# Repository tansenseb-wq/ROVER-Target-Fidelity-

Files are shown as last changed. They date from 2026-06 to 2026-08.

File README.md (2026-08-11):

# ROVER "Target Fidelity"

A low-budget, 6-wheel autonomous rover that drives itself through rough terrain, collects soil and plant samples, and runs onboard biology and geology tests — all built from 3D-printed parts, off-the-shelf motors, and open-source software. Or so I hope.

## Status

No driving demo yet — here's where the build actually stands:

| Area | State |
|---|---|
| Suspension + wheel-corner CAD | Designed and validated as standalone assemblies (steering geometry, printed bearing, real angles) |
| Differential (balancín + bieletas) | Geometry defined (325 mm 1:1 ratio); hardware not sourced yet |
| BOM | Mobility, chassis frame, filament, and the brain are priced in a real quote; chassis panels, battery, and lab hardware still need quotes |
| Firmware | Not started |
| Sampling arm / lab / vision | CAD and hardware selection in progress, no integration yet |

See the steering knuckle actually moving in [Wheel-corner assembly](#wheel-corner-assembly) below.

---

## What it does

- **Drives itself** — autonomous navigation with SLAM mapping and AR marker detection
- **Handles rough terrain** — rocker-bogie passive suspension (inspired by JPL's open-source rover) keeps all 6 wheels on the ground on dirt, gravel, and grass
- **Real differential** — a balancín + bieletas linkage (like the actual JPL rover) keeps the chassis level when the two sides climb at different heights
- **Collects samples** — a 3-DOF robotic arm with a soil scoop and sealed sample container, controlled by inverse kinematics
- **Runs field biology** — automated Biuret protein test (CuSO₄ + NaOH mix) and plant pigment detection, read by an onboard RGB color sensor
- **Measures soil moisture** — capacitive sensor for real-time geology data
- **Can be driven remotely** — full teleop mode with live camera feed over local WiFi

---

## Key specs

| Spec | Value |
|---|---|
| Chassis body | 900 × 600 mm |
| Wheelbase | 1000 mm |
| Wheel diameter | 200 mm |
| Top speed | ~150 mm/s |
| Obstacle clearance | 300 mm (1.5× wheel Ø) |
| Ground clearance | ~248 mm |
| Estimated mass | ~30 kg |
| Suspension | Passive rocker-bogie, 6 wheels |
| Differential | Real (balancín + bieletas, chassis-leveling) |
| Steering | 4 corner wheels (servo) |

---

## Subsystems

| Subsystem | Key components |
|---|---|
| Chassis | Aluminum 2020 extrusion + PLA/PETG 3D-printed joints |
| Mobility | 6× JGB37 DC motors, BTS7960 drivers, TPU wheels, 2× 448 CPR optical encoders |
| Differential | Balancín + 2 bieletas with ball-joint ends |
| Steering | 4× MG995R servos + PCA9685, printed-bearing knuckle (see below) |
| Brain | Arduino UNO Q (Linux Cortex-A53 + realtime Cortex-M33, one board) |
| Vision | WIP |
| Navigation | WIP |
| Sampling arm | 4× SG51R mini servos, WIP structure |
| Lab | TCS34725 color sensor, peristaltic pump, syringe dispenser |
| Geology | Capacitive soil moisture sensor |

---

## Wheel-corner assembly

Each steering wheel (front-left/right, rear-left/right) is a servo, a printed knuckle, a coupler, and the wheel itself, all validated as a standalone assembly (`Ensamble llanta` / `Ensamble llanta Largo`) before going into the full rover.

- **Geometry adapted from a proven reference** — the servo coupler, servo horn, and wheel-joint pieces come from the "Mars Rover Perseverance Replica" build rather than being designed from scratch. The 37 mm gearmotor (6 mm D-shaft, 31 mm bolt circle) drops straight into the reference's wheel-joint cavity with no scaling.
- **Printed bearing, not a bought one** — the knuckle carries a print-in-place ball bearing (OpenSCAD + BOSL2, "635" size: ID5/OD19/W6mm, dumbbell rollers) instead of a purchased bearing.
- **Socket angle comes from the live model** — the socket tilts so the servo's steering axis is exactly vertical despite sitting on an angled rocker/bogie arm: **30°** at the front/rocker corner, **10°** at the rear/bogie corner, both measured from the actual Fusion assembly rather than assumed.
- **Mirrored for both sides** — all three knuckle variants (`JuntaLlanta`, `JuntaLlantaEstatica`, `JuntaLlantaDireccion`) have mirrored left-side counterparts (`...I` suffix) so the 6-wheel layout is symmetric.

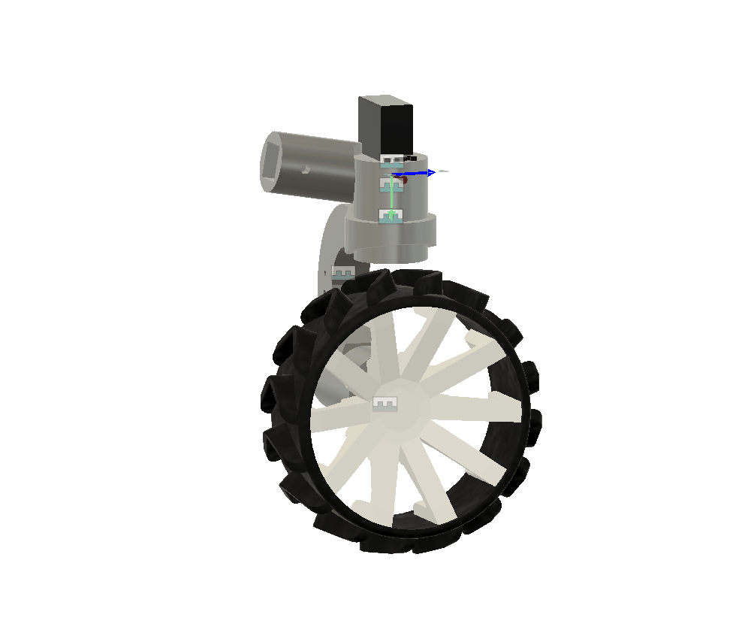
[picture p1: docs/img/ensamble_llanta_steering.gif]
Steering geometry in motion — one wheel-corner assembly sweeping through its steering range


*The steering knuckle (servo + printed bearing + wheel) swinging through its range in Fusion, captured directly from the live model. Full field-test footage still coming.*

---

## Bill of Materials

[`BOM/bom_rover.csv`](BOM/bom_rover.csv) lists every part that's actually been priced, with real quantities, real COP prices, and where each one mounts on the rover — comma-delimited, one quote as the single source of truth (no placeholder/estimate rows).

**Cotizado** (priced out in a real quote — Cotización S174842, I+D Didácticas Electrónicas, COP $2,216,852 with IVA, nothing purchased yet): all 6 JGB37 motors + 3 BTS7960 drivers + steering/arm servos + PCA9685, 13 m of 2020 aluminum profile + T-nuts, PETG/TPU filament, the Arduino UNO Q brain, 2× 448 CPR optical encoders, plus assorted cabling and small hardware.

**Still needed but not priced yet:** round aluminum tube + steel axle for the differential, the acrylic/MDF lid, the LiPo battery + charger, and the lab-module hardware (color sensor, pumps, syringe dispenser) — left out of the CSV until there's a real quote for them, rather than carrying rough guesses.

---

## Printed parts — quick guide

### A couple of things worth knowing before printing

- **The joints set all the angles**, so the aluminum tubes are cut straight at 90°. No mitering needed — that's the whole point of the printed joints.
- **All three wheel mounts share the same 90 mm drop** (socket to wheel center). That's what keeps the three wheels level on the ground — don't change it on just one.
- **The differential bieletas need ball joints on both ends** — a rigid connection binds the linkage. The 1:1 ratio (balancín arm = clamp offset = 325 mm, measured off the real `Diferencial` part) is what keeps the leveling symmetric.
- **Joint walls are 5 mm** — don't go thinner or the M5 bolts pull out of the PETG under load.

Print-ready STL files for every finished functional part live in [`Parts/STL-parts`](Parts/STL-parts), organized by subsystem (`Bogie`, `Direccion`, `Llantas`) rather than by print settings — CAD source stays in Fusion, this folder is just the slicer-ready output.

---

## Build journal

The full design log — why rocker-bogie, the math behind the geometry, dead ends, and every decision along the way — is in [`Journal/Librito_Rover x_x (CreacionSistemaMecanico) .pptx`](Journal/Librito_Rover%20x_x%20%28CreacionSistemaMecanico%29%20.pptx). It's a running notebook, not a polished report; open it in PowerPoint/Slides to read or add to it.

---

## Credits

- Suspension design heavily inspired by [NASA JPL Open Source Rover](https://github.com/nasa-jpl/open-source-rover) 

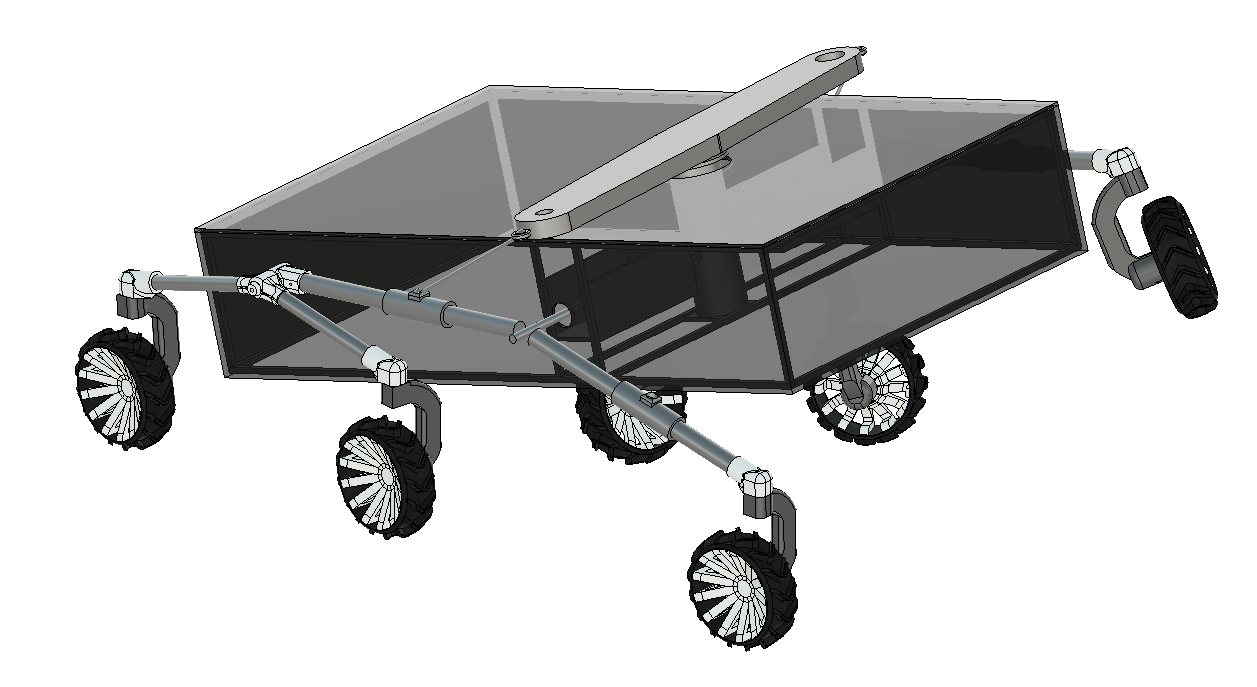
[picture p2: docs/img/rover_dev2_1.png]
Rover dev 2 — isometric view


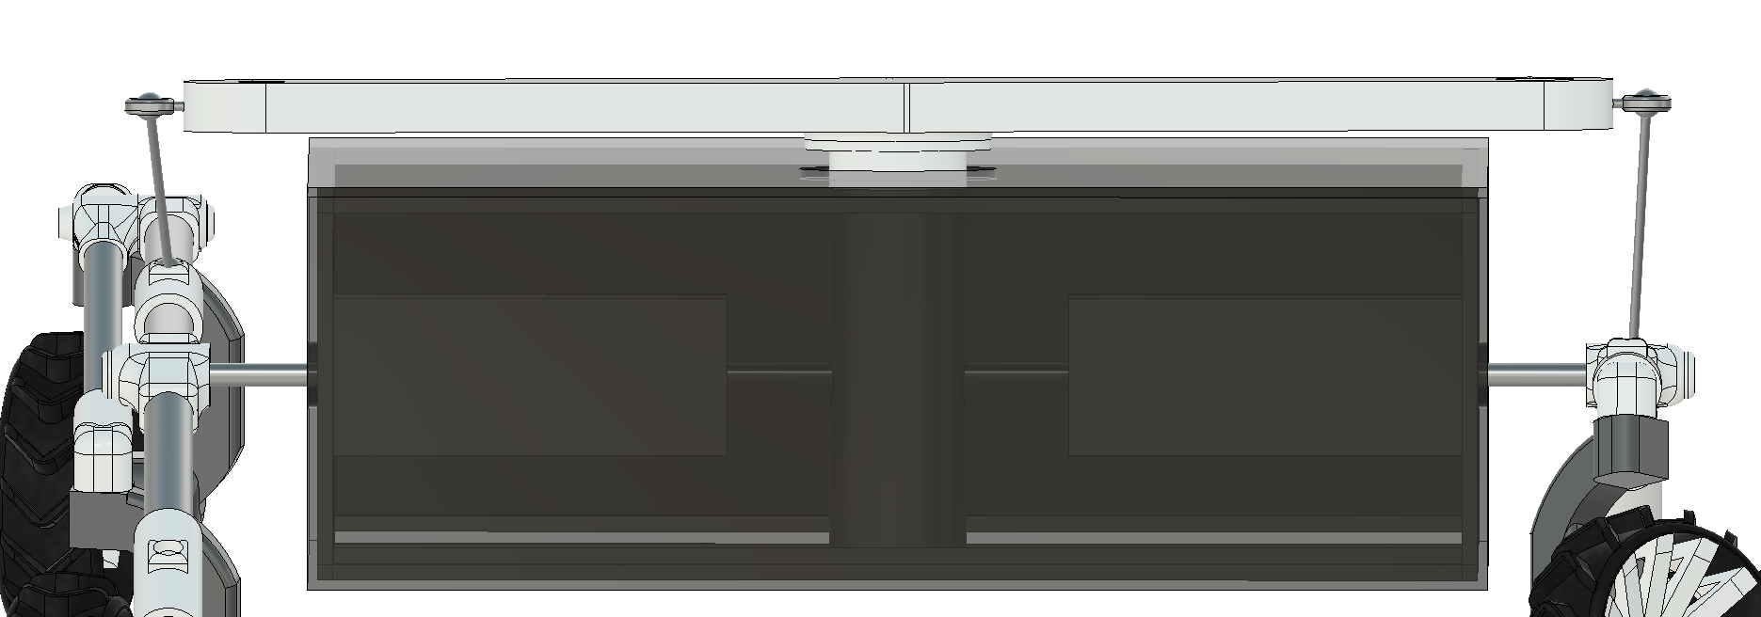
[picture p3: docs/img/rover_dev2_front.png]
Rover dev 2 — front view showing the differential


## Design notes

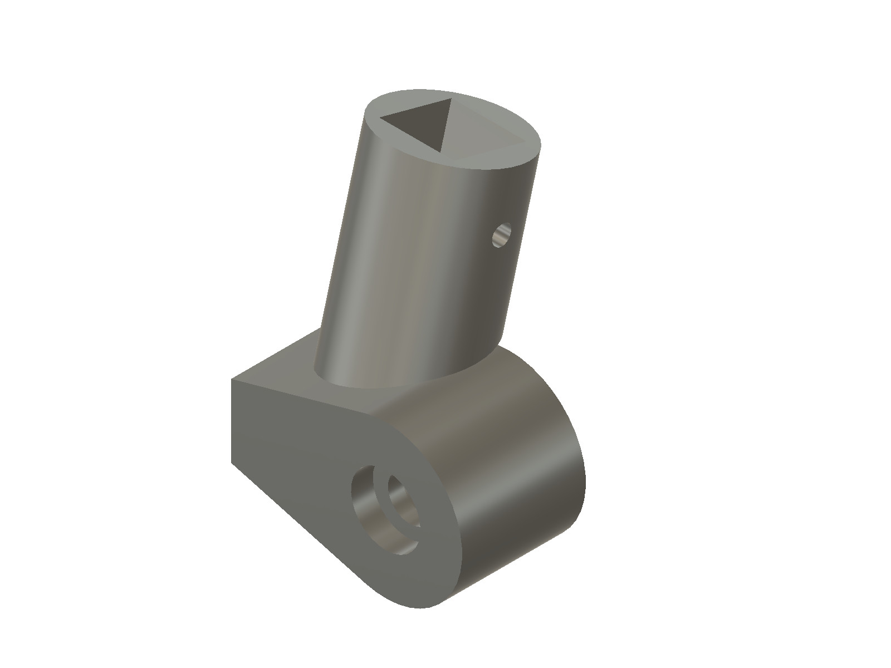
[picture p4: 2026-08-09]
docs/img/junta_llanta_direccion.png

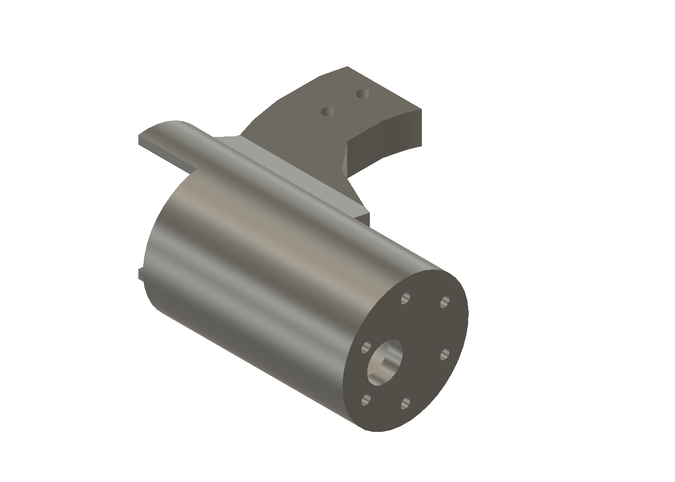
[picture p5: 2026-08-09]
docs/img/wheel1_joint_p2_motor_mount.png

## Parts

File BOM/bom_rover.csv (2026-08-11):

Categoria | Parte | Cantidad | PrecioUnitario_COP | Subtotal_COP | Fuente | Estado | Montaje
Movilidad | Motorreductor JGB37 12V 100RPM | 6 | 73613 | 441678 | ELECTRONICA I+D S.A.S. (Cotizacion S174842) | Cotizado | Junta de rueda (Bogie) - motor de cada una de las 6 ruedas
Movilidad | Driver BTS7960 43A | 3 | 29076 | 87228 | ELECTRONICA I+D S.A.S. (Cotizacion S174842) | Cotizado | Chasis interior - placa de electronica de potencia
Movilidad | Servo MG995R 4.8-7.2V 13Kg/cm (direccion, 4 ruedas) | 4 | 20700 | 82800 | ELECTRONICA I+D S.A.S. (Cotizacion S174842) | Cotizado | Junta de rueda (Bogie) - direccion de las 4 ruedas de esquina
Movilidad | Controlador PCA9685 (16 ch PWM, sin ensamblar) | 1 | 15126 | 15126 | ELECTRONICA I+D S.A.S. (Cotizacion S174842) | Cotizado | Chasis interior - placa de electronica, junto al Arduino UNO Q
Movilidad | Eje metalico [EJE-1005] 100x5 mm | 3 | 2904 | 8712 | ELECTRONICA I+D S.A.S. (Cotizacion S174842) | Cotizado | Junta de rueda (Bogie) - eje servo-rodamiento-rueda en JuntaLlantaDireccion/JuntaLlanta
Movilidad | Rodamiento con brida MF105ZZ (ID5/OD10/H4 mm) | 5 | 3388 | 16940 | ELECTRONICA I+D S.A.S. (Cotizacion S174842) | Cotizado | Junta de rueda (Bogie) - soporte del eje
Movilidad | Encoder optico 448 CPR (eje de 37 mm, para motorreductor) | 2 | 32900 | 65800 | ELECTRONICA I+D S.A.S. (Cotizacion S174842) | Cotizado | Junta de rueda (Bogie) - acoplado al eje trasero del motorreductor
Chasis | Perfil aluminio 2020V-N2 (por m, CNC) | 13 | 24923 | 323995 | ELECTRONICA I+D S.A.S. (Cotizacion S174842) | Cotizado | Chasis - marco estructural
Chasis | Tornillo en T M5x12 para perfil 2020 | 20 | 756 | 15120 | ELECTRONICA I+D S.A.S. (Cotizacion S174842) | Cotizado | Chasis - union de perfiles y placas
Impresion 3D | Filamento PETG Blanco 1kg | 1 | 70300 | 70300 | ELECTRONICA I+D S.A.S. (Cotizacion S174842) | Cotizado | Consumible - no se monta
Impresion 3D | Filamento PETG Gris 1kg | 2 | 70300 | 140600 | ELECTRONICA I+D S.A.S. (Cotizacion S174842) | Cotizado | Consumible - no se monta
Impresion 3D | Filamento TPU 95A Negro 800g | 1 | 90800 | 90800 | ELECTRONICA I+D S.A.S. (Cotizacion S174842) | Cotizado | Consumible - no se monta
Cerebro y control | Arduino UNO Q (RAM 2GB, eMMC 16GB, Cortex-A53 + Cortex-M33) | 1 | 189000 | 189000 | ELECTRONICA I+D S.A.S. (Cotizacion S174842, 10% desc.) | Cotizado | Chasis interior - placa de electronica (cerebro)
Cerebro y control | Pantalla OLED 2.42" SSD1309 Blanco | 1 | 45546 | 45546 | ELECTRONICA I+D S.A.S. (Cotizacion S174842) | Cotizado | Chasis - panel frontal/superior visible
Cerebro y control | Conversor DC/DC reductor 300W 20A (alimentacion principal) | 1 | 22185 | 22185 | ELECTRONICA I+D S.A.S. (Cotizacion S174842) | Cotizado | Chasis interior - compartimento de energia
Cerebro y control | Modulo conversor DC-DC LM2576HV (salida ajustable, 3A) | 1 | 11900 | 11900 | ELECTRONICA I+D S.A.S. (Cotizacion S174842) | Cotizado | Chasis interior - compartimento de energia
Energia | Cable siliconado 10AWG Rojo (bateria) | 1 | 18824 | 18824 | ELECTRONICA I+D S.A.S. (Cotizacion S174842) | Cotizado | Chasis interior - linea principal de bateria
Electronica y cableado | Dispensador de cable siliconado 18AWG (5 colores) | 1 | 43697 | 43697 | ELECTRONICA I+D S.A.S. (Cotizacion S174842) | Cotizado | Chasis interior - junto a la placa de electronica
Electronica y cableado | Cable Dupont M/M 10cm (paquete x10, colores) | 3 | 1700 | 5100 | ELECTRONICA I+D S.A.S. (Cotizacion S174842) | Cotizado | Chasis interior - junto a la placa de electronica
Electronica y cableado | Cable Dupont M/H 10cm (paquete x10, colores) | 3 | 1700 | 5100 | ELECTRONICA I+D S.A.S. (Cotizacion S174842) | Cotizado | Chasis interior - junto a la placa de electronica
Electronica y cableado | Pelacable multifuncional AWG 22-10 | 1 | 12600 | 12600 | ELECTRONICA I+D S.A.S. (Cotizacion S174842) | Cotizado | Chasis interior - junto a la placa de electronica
Laboratorio | Varilla trapezoidal roscada M8 paso 1mm, 1m (husillo dispensador/jeringa) | 1 | 39100 | 39100 | ELECTRONICA I+D S.A.S. (Cotizacion S174842) | Cotizado | Modulo de laboratorio - husillo del dispensador de jeringa
Brazo de muestreo | Mini servo SG51R Tower Pro 5g (brazo) | 4 | 24200 | 96800 | ELECTRONICA I+D S.A.S. (Cotizacion S174842) | Cotizado | Brazo de muestreo (frontal del chasis)
Logistica | Envio Mensajero (Medellin) | 1 | 13950 | 13950 | ELECTRONICA I+D S.A.S. (Cotizacion S174842) | Cotizado | N/A - logistica, no se monta

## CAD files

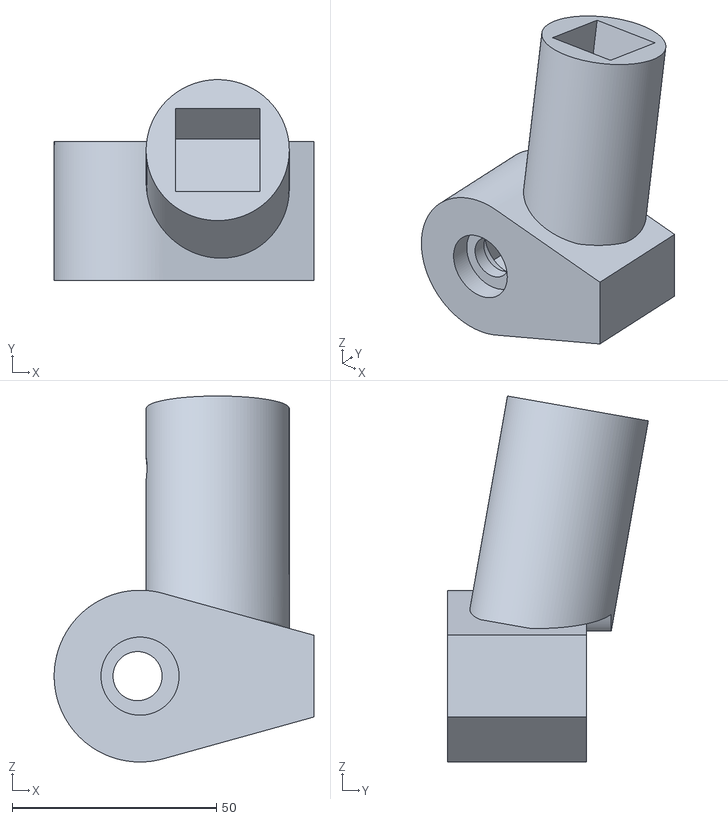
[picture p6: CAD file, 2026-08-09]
Parts/STL-parts/Bogie/JuntaLlantaI.stl
63.5 x 49.1 x 89.5

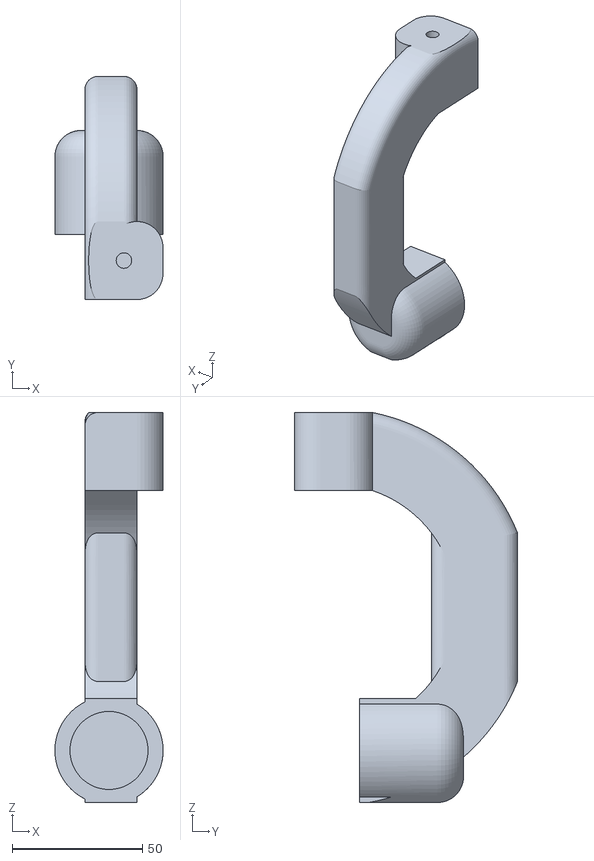
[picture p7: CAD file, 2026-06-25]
Parts/STL-parts/Direccion/Direccion_Izq.stl
41.6 x 85.8 x 149.9

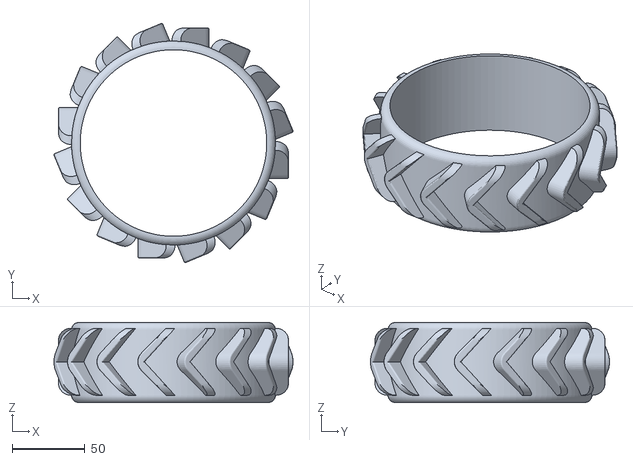
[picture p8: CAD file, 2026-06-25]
Parts/STL-parts/Llantas/Neumatico.stl
164.1 x 164.1 x 55.0

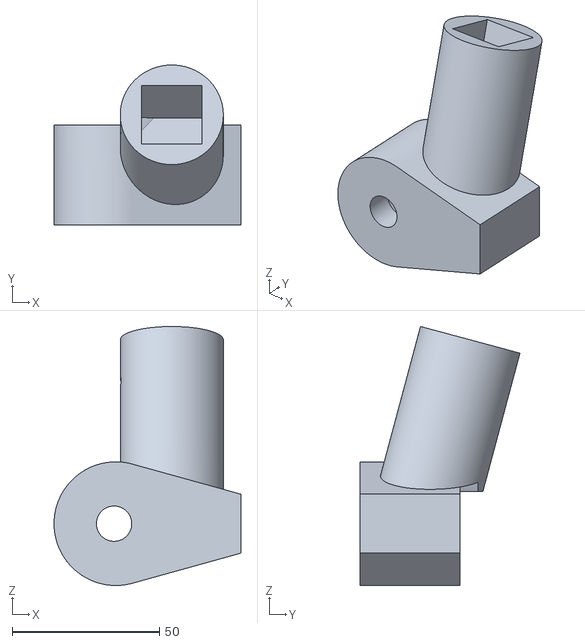
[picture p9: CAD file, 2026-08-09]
Parts/STL-parts/Bogie/JuntaLlantaEstaticaI.stl
63.5 x 54.3 x 88.0

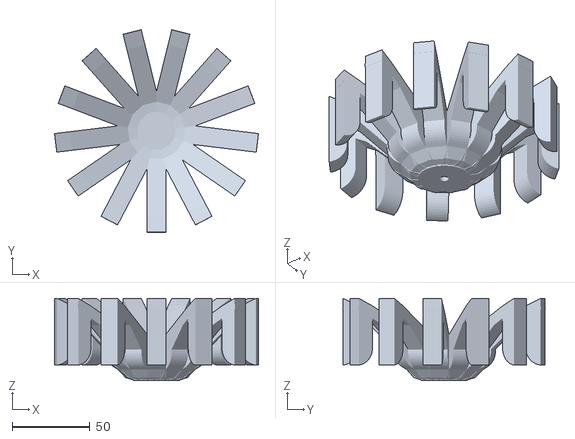
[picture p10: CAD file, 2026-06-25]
Parts/STL-parts/Llantas/Rin.stl
130.9 x 129.9 x 52.8

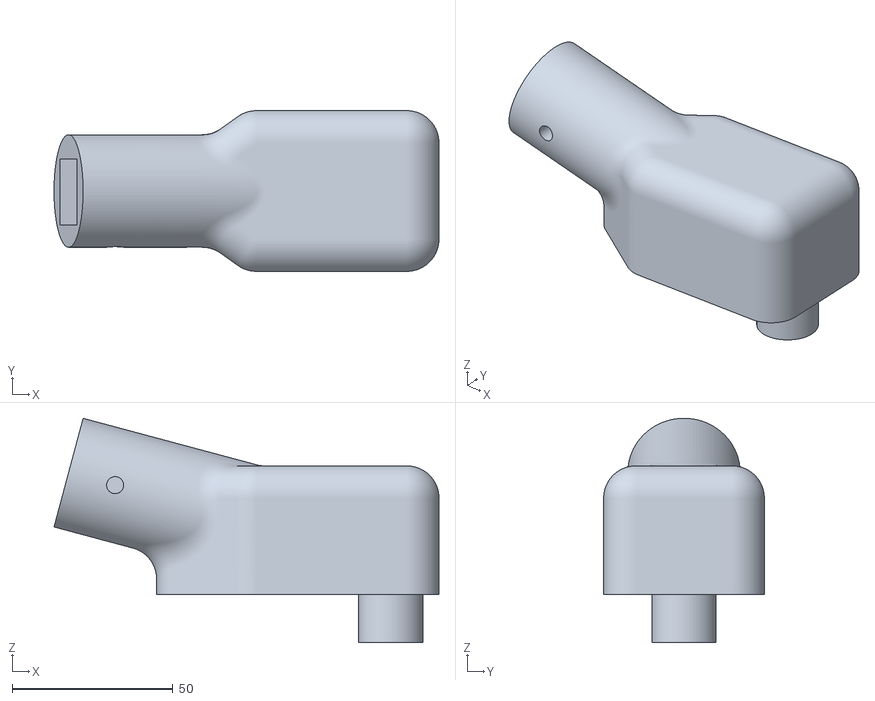
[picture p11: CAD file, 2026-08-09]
Parts/STL-parts/Bogie/JuntaLlantaEstatica.stl
119.8 x 50.0 x 69.8

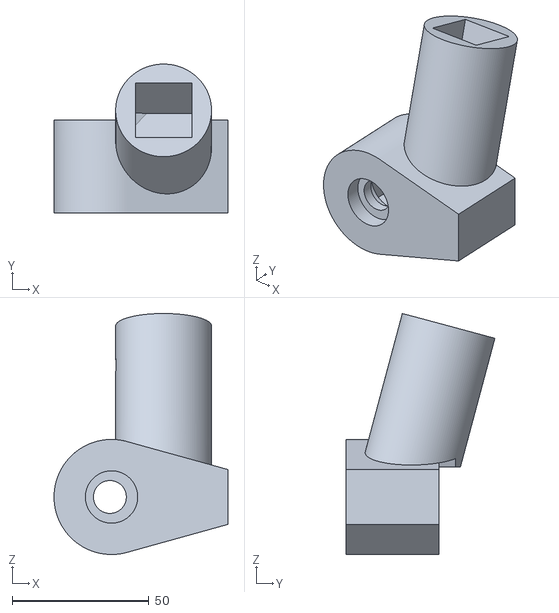
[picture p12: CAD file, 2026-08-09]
Parts/STL-parts/Bogie/JuntaLlantaDireccionI.stl
63.5 x 54.3 x 88.0

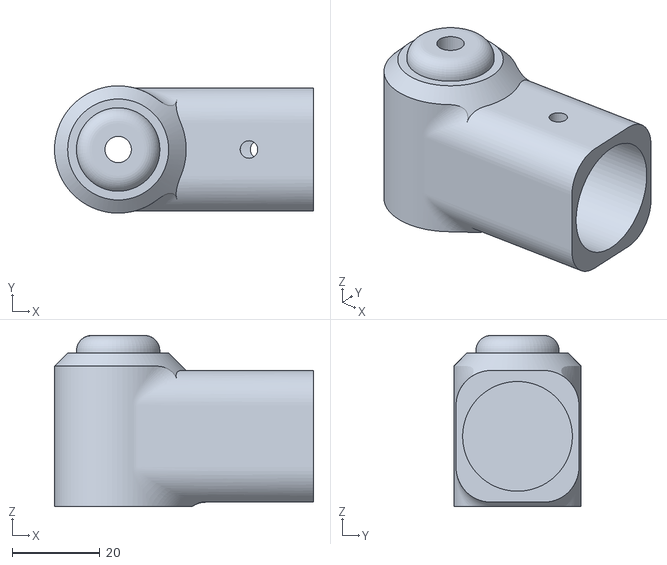
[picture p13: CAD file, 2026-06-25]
Parts/STL-parts/Bogie/JuntadelBogie.stl
59.0 x 29.0 x 39.0

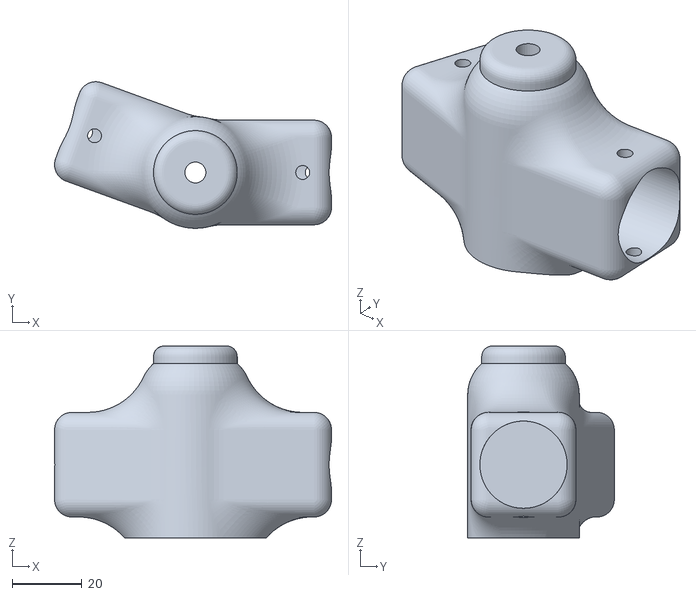
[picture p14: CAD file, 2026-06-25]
Parts/STL-parts/Bogie/Junta_A.stl
79.4 x 42.0 x 55.0

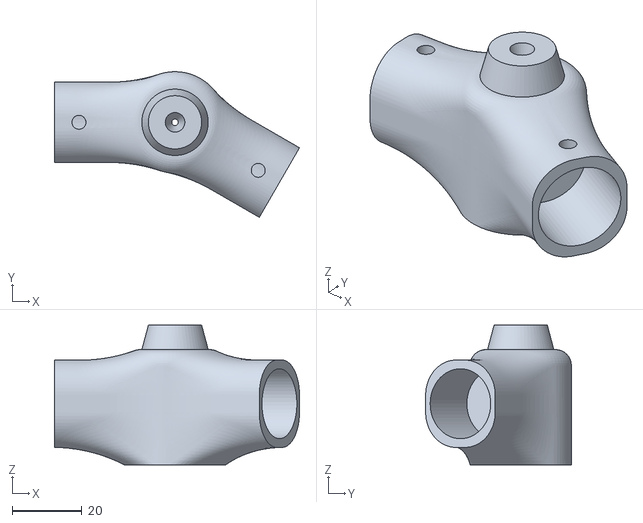
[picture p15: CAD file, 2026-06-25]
Parts/STL-parts/Bogie/Junta_B.stl
70.1 x 41.7 x 40.0

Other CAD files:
Parts/STL-parts/Direccion/Direccion_Der.stl
Parts/STL-parts/Bogie/JuntaLlanta.stl
Parts/STL-parts/Bogie/JuntaLlantaDireccion.stl

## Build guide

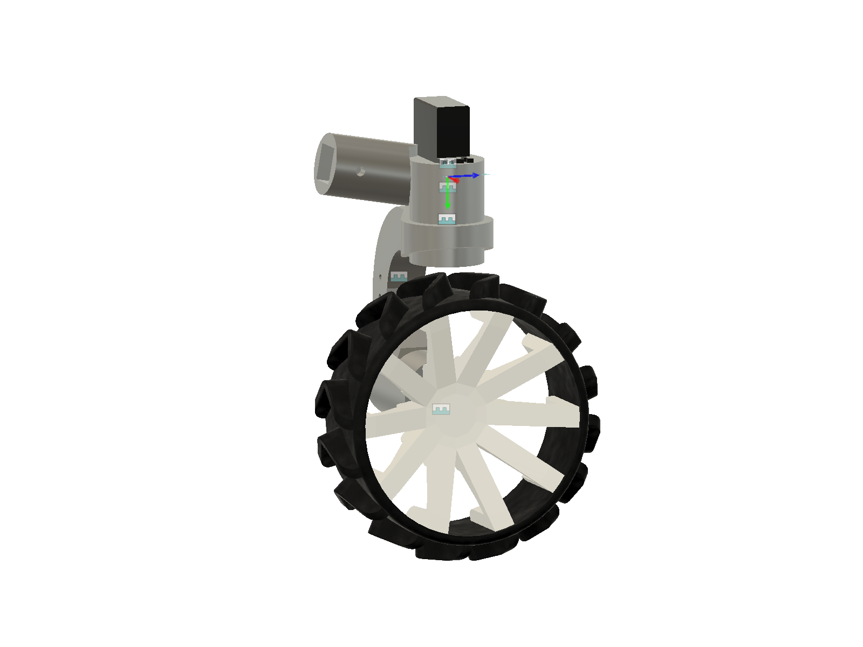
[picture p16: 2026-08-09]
docs/img/ensamble_llanta_largo.png

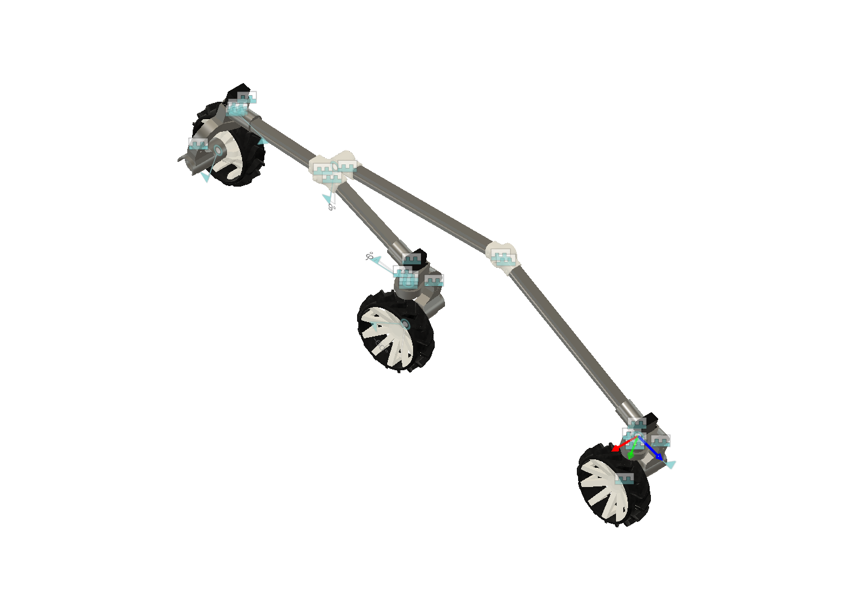
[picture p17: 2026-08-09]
docs/img/ensamble_lateral_arms.png

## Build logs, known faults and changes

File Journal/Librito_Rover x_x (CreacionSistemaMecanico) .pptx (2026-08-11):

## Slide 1

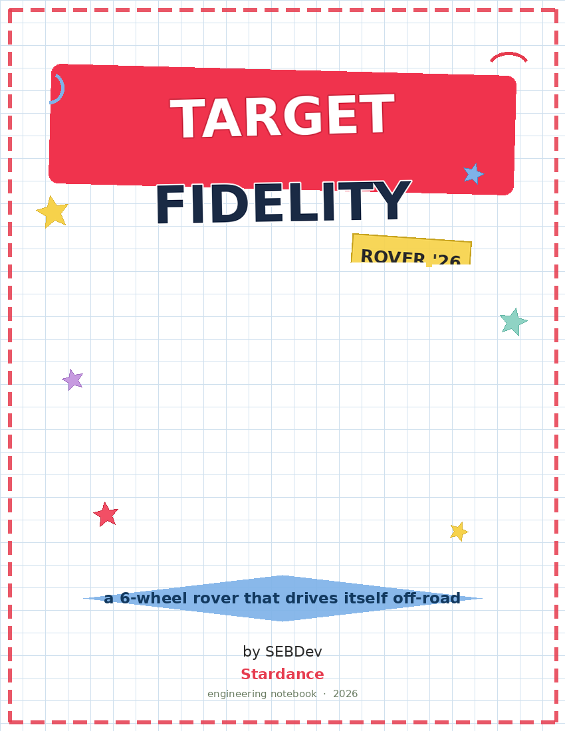
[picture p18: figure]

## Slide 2

Table of Contents

Page | Entry | Date
3 | What I'm building & why | 06/30/2026
4 | The targets I set | 06/30/2026
5 | Digging into rocker-bogie | 06/30/2026
6 | Running the geometry | 06/30/2026
7 | Loads & how high it can climb | 06/30/2026
8 | Going round tube + printed joints | 06/30/2026
9 | The differential mess | 06/30/2026
10 | Nailing the differential geometry | 06/30/2026
11 | Steering & getting the wheels level | 06/30/2026
12 | Shrinking the chassis to 900x600 | 06/30/2026
13 | Picking motors & battery | 06/30/2026
14 | My FEA plan (targets) | 06/30/2026
15 | Bill of materials | 06/30/2026
16 | Redesigning the wheel joint: bearing + real angles | 08/09/2026
17 | Getting a real quote for the shopping list | 08/09/2026
18 | Where I'm at & what's next | 08/09/2026

Project: ROVER "Target Fidelity"

Name: SEBDev

Date: 06/30/2026

Page 1

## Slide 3

What I'm building & why

The idea

I'm building a low-cost 6-wheel rover that drives itself over rough ground - dirt, gravel, grass - grabs soil and plant samples on its own, and runs actual biology and geology tests onboard. Basically a tiny Mars rover, except I'm doing it with a 3D printer, cheap motors, and a Raspberry Pi instead of a NASA budget. This notebook is my movement/suspension system: how I got from "I want a rover" to an actual Fusion model.

- drive itself - SLAM mapping + AR marker detection
- survive rough terrain - passive rocker-bogie keeps all 6 wheels down
- collect samples - 3-DOF arm with a scoop + sealed container
- run field biology - Biuret protein test + pigment detection with an RGB sensor
- read soil moisture - capacitive sensor
- fall back to teleop - live camera over local WiFi

What it needs to do

Why rocker-bogie

I went with rocker-bogie because it's what the real Mars rovers use (Sojourner, Curiosity, Perseverance). It's fully passive - no springs, no shocks - and the geometry alone keeps at least 4 wheels on the ground no matter how rough it gets. For a rover carrying a delicate onboard lab across unpredictable ground, that's exactly what I want.


Project: ROVER "Target Fidelity"

Name: SEBDev

Date: 06/30/2026

Page 3

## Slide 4

The targets I set

Before touching any math I pinned down what the rover actually had to hit:

ID | What | Target
R-01 | Chassis width | 600 mm
R-02 | Chassis length | 900 m
R-03 | Speed | 150 mm/s
R-04 | Obstacle it can climb | 300 mm (1.5 x wheel D)
R-05 | Driven wheels | 6 (3 per side)
R-06 | Suspension | passive rocker-bogie
R-07 | Steering | servos on the 4 corner wheels
R-08 | Terrain | dirt, gravel, grass
R-09 | Working mass | ~30 kg

The mass kept climbing
I started guessing ~22 kg, then bumped it to 30 kg to be safe once I counted the aluminum frame, the onboard lab, and the sampling arm. That 30 kg is what drove my motor and battery choices later (page 13).

Wheelbase != chassis length
Big realization: I stopped tying the wheelbase to the chassis length. Keeping them independent is what let me shrink the body to 900 mm while keeping a 1000 mm wheelbase - so the wheels wrap the body.

Project: ROVER "Target Fidelity"

Name: SEBDev

Date: 06/30/2026

Page 4

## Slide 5

Digging into rocker-bogie

What I read

I didn't want to wing the suspension, so I dug in. Verma et al. (2017) gave me the sizing formulas. Singh & Jain (2020) covered how the load spreads and how the thing climbs. And I went through NASA JPL's Open Source Rover docs to see how they actually build the differential and joints.

6-wheel 3-3 layout keeps >=4 wheels grounded at all times.
It's fully passive - the geometry does everything, no springs.
Bogie pivot position sets how load splits: Case 1 (offset) = 0.21/0.39/0.40, Case 2 (centered) = 0.30/0.30/0.40.

I went Case 2 (centered bogie pivot). Splitting the load evenly between the front and middle wheels means less chance one spins out on loose dirt. Either way the rear wheel carries 40%, which told me the rocker arm is the part I'd need to stress-test hardest.

The formulas I pulled from Verma
V = pi*D*N/60 (wheel speed) . L = reach/cos(theta) (arm length) . h = reach*tan(theta) (arm height). They used 45deg for climbing stairs; I used gentler 10-15deg since I'm on open ground. Their rule that the differential bar = chassis width is where my axle span came from.

What stuck with me

What I chose

Project: ROVER "Target Fidelity"

Name: SEBDev

Date: 06/30/2026

Page 5

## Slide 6

Running the geometry

Wheel speed

N = 60*V / (pi*D) = 60 x 150 / (pi x 200) = 14.32 rpm

So I need ~14.3 rpm at the wheel. Easy for the JGB37 motors - I just regulate down with PWM.

Point | X (mm) | Note
Front W1 | 0 | reference
Middle W2 | 430 | same load as front
Rear W3 | 1000 | end of wheelbase
Bogie pivot | 215 | centered W1-W2
Chassis pivot | 615 | rocker meets chassis

Where the wheels sit

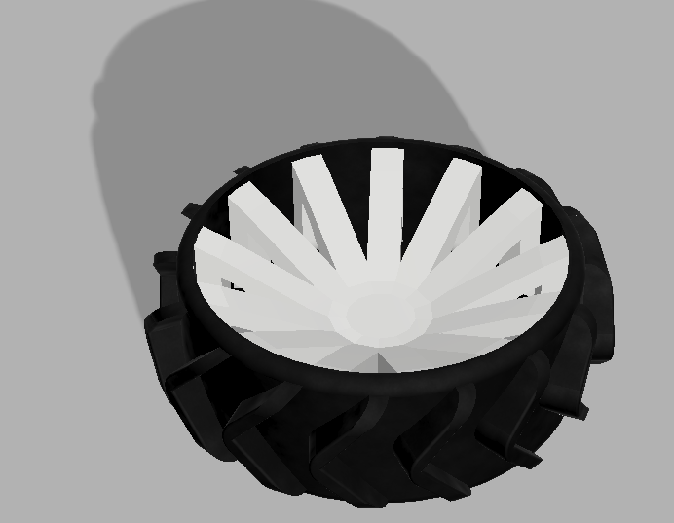
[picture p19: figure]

Arms & angles

Bogie (theta=15deg): L = 215/cos15 = 223 mm, h = 57.6 mm -> Joint B at 150deg
Rocker (theta=10deg): Seg-A 401, Seg-B 396 (~800 total) -> Joint A at 160deg

Cut lengths aren't the same as center-to-center
The lengths above are geometry. When I actually cut tube I subtract what slides into each printed joint: Seg-A 345, Seg-B 366, bogie 202 (Joint A eats 26, chassis fitting 30, Joint B 21).


Project: ROVER "Target Fidelity"

Name: SEBDev

Date: 06/30/2026

Page 6

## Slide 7

Loads & how high it can climb

Loads at 30 kg

W = m*g = 30 x 9.81 = 294.3 N
R3 (rear) = 0.40*W = 117.7 N <- the heavy one
R1 = R2 = 0.30*W = 88.3 N

With a x2 dynamic factor for terrain shocks, the rocker sees ~235 N and the bogie ~177 N. Those are the numbers I'll feed the FEA (page 14).

My target is 300 mm = 1.5 x wheel D. The theoretical max for rocker-bogie is 2 x D = 400 mm. So I'm at 75% of the ceiling - a comfy 1.33 margin. I'll take it.

How high it climbs

Ground clearance

Base clearance is h_bogie + R ~ 158 mm. But my wheel mounts drop the wheels 90 mm, which lifts the chassis, so real clearance ends up ~248 mm. More clearance for obstacles, slightly higher CG - fine for terrain without crazy side slopes.

A note to myself on the load split
The 0.30/0.30/0.40 numbers sum to 1.0 over a 3-wheel train. For the FEA I'm treating them as a worst-case load dumped on one wheel, not an average - better to over-build than find out the hard way.

Project: ROVER "Target Fidelity"

Name: SEBDev

Date: 06/30/2026

Page 7

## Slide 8

Going round tube + printed joints

The switch

I moved the arms from square tube to round aluminum tube, and made every intersection a 3D-printed PETG joint instead of bending tube or bolting plates. Round tube is easier to source and easier to bond into the joints.

Tube | Profile | Cut length | Qty
Rocker Seg-A | D25 x 2 mm | 345 mm | 2
Rocker Seg-B | D25 x 2 mm | 366 mm | 2
Bogie arm | D20 x 2 mm | 202 mm | 4

Joint | Sockets | Angle | Wall
A (rocker) | 2 | 160deg | 5 mm
B (bogie) | 2 | 150deg | 5 mm


Why I like this
The joints hold the angles, so I cut every tube dead straight at 90deg - no mitering, no bending jigs. I print them PETG, 5 perimeters, 60% infill, socket-up, no supports. Tubes press-fit and pin with 2x M5 each.

Bushing, not bearing
The D12 axle rides through the boss on a printed plain bushing (greased), not a ball bearing - cheaper and fine for a passive axle. I keep the wall at 5 mm; any thinner and the M5 bolts rip out of the PETG.

Project: ROVER "Target Fidelity"

Name: SEBDev

Date: 06/30/2026

Page 8

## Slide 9

The differential mess

Where I went wrong

My first "differential" was just a rigid bar. Reading the JPL docs again, it hit me - that's not actually a differential. A rigid bar doesn't level the chassis; each side just does its own thing. A real one connects both rockers so when one climbs, the other drops and the body stays level. I'd been missing the whole point of the mechanism.

A central hub that rocks, two turnbuckles (threaded rods with ball-joint ends), and links to each rocker. Chain: rocker -> turnbuckle -> rocking hub -> turnbuckle -> other rocker. The Hackaday writeup literally calls this the crucial link that most DIY rovers skip because it's fiddly - and they lose capability for skipping it.

How NASA does it

The thing I finally understood

There are two separate things: the transverse D12 axle (just the pivot the rockers turn on) and the balancin + bieletas on top (the mechanism that actually levels the chassis). My earlier design only had the axle. I'd left out the leveling entirely.

Decision - build the real one
For a competition rover where rough terrain is the whole point, real leveling is worth the extra parts. I went with a printed version of NASA's mechanism: a balancin that rocks, two bieletas down to clamps on the rockers. Got it moving right in the Fusion Motion Study.

Project: ROVER "Target Fidelity"

Name: SEBDev

Date: 06/30/2026

Page 9

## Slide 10

Nailing the differential geometry

Element | What I settled on
Balancin length | 360 mm total
Balancin arm (center -> bielle hole) | 180 mm each side
Balancin pivot | D8 (M8), longitudinal axis
Clamp on rocker tube | one per rocker (2 total)
Clamp offset from rocker axis | 180 mm (= balancin arm)
Clamp position from tube start | 170 mm along the tube
Bieleta length | ~253 mm center-to-center
Bieleta ends | ball joints on BOTH ends
Ratio | 1:1

Balancin arm (180) has to equal the clamp offset (180). If they're not equal, one side moves more than the other and the leveling goes lopsided. The bieleta length doesn't touch the ratio - it just spans the gap. Took me a couple wrong guesses (I had it at 350 once) to get this.

The 1:1 rule I learned

Ball joints on both ends
The balancin rocks in one plane, the rocker turns in another. Rigid ends bind it. Rod-end (Heim) joints on both ends of each bieleta soak up the angle - 4 rod-ends total.

Mounted on top
The whole differential sits on top of the lid, outside the sealed body - only the D12 axle enters the box. That fixed the bieletas clipping the chassis edge; they now run outside the box.


Project: ROVER "Target Fidelity"

Name: SEBDev

Date: 06/30/2026

Page 10

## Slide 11

Steering & getting the wheels level

All the same mount

I ended up using the same C-mount body for all 6 wheels. The only difference is the servo: the 4 corner wheels get an MG996R on top for steering (vertical axis), and the 2 middle wheels use the same mount with no servo - fixed.

Mount | Tube | Tilt | Rotate
Front (steered) | Bogie | 15deg | -15 -> 75
Middle (fixed) | Bogie | 15deg | -15 -> 75
Rear (steered) | Rocker B | 10deg | -10 -> 80

Socket angles to keep wheels vertical

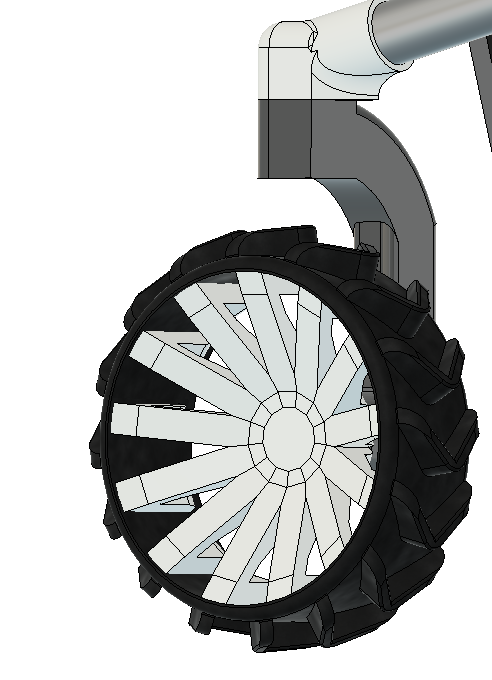
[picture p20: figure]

Getting them level

All three mounts on a side share the same 90 mm drop (socket -> wheel center). Same H on all three = wheels come out level on their own. 90 mm gives room for the servo above the corner wheels, and the middle mount just copies it even though it has no servo.

Shop trick
Instead of measuring angles off the tube, I just orient each socket so the mount hangs plumb (checked with a level) when the rover sits flat. Then the servo axis is vertical automatically. I'll design the mounts with slotted holes so final leveling is a slide-and-tighten on a flat surface.

Project: ROVER "Target Fidelity"

Name: SEBDev

Date: 06/30/2026

Page 11

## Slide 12

Shrinking the chassis to 900x600

What I wanted

I wanted the body to tuck inside the wheels, like Curiosity, instead of the wheels sitting inside the body. The realization: this needs wheelbase > chassis length. Moving the pivot alone can't do it - the pivot just slides the body forward/back, it can't change which one is bigger.

| Grow wheelbase | Shrink chassis
I change | the suspension | only the chassis
Wheelbase | 1400 mm | 1000 (same)
Chassis | 1200 mm | 900 mm
Rover size | bigger ~1500 | compact ~1100
Recalc arms? | yes | no

Two ways to do it

What I picked

Since 1200 mm turned out not to be a hard requirement, I shrank the chassis to 900 mm - it's the simpler move and doesn't touch the suspension. Now wheelbase (1000) > chassis (900), so the wheels wrap the body by 50 mm each end. The differential pivot lands ~108 mm behind chassis center, which loads the rear a bit (helps climbing).

What survived the change
All the arm lengths, angles, joints, loads, and the axle span are tied to the wheelbase (unchanged), so they all held. Only the old wheelbase-from-chassis formula broke - now they're independent, which is the whole point.

Project: ROVER "Target Fidelity"

Name: SEBDev

Date: 06/30/2026

Page 12

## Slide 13

Picking motors & battery

The speed problem

A D200 wheel at 100 rpm is ~1050 mm/s - 7x too fast vs my 150 target. So I need low-rpm, high-torque motors and I regulate down with PWM.

~18-25 kg*cm/wheel for a 30deg slope (6 wheels), up to ~50 worst case (3 wheels gripping). I picked the JGB37 50RPM that does 40 kg*cm - good for normal terrain, tight for big obstacles.

What | Choice | Qty | ~COP | Where
Motor | JGB37 12V 50RPM (40 kg*cm) | 6 | $87,600 | I+D
Driver | BTS7960 43A | 2 | $25,000 | I+D
Servo driver | PCA9685 | 1 | $20,000 | I+D/Big
Servo | MG996R | 4 | $26,000 | Bigtronica
Battery | LiPo 8-10 Ah 12V | 1 | varies | -

Torque check at 30 kg

Battery

At 30 kg I pull ~12.5 A nominal, ~26 A peak when climbing. A LiPo handles those peaks easily and gives ~40 min at 8-10 Ah. I could do 2x SLA 12V 12Ah but they're heavy.

still need to check - encoder
The 40 kg*cm listing at I+D doesn't clearly say it has an encoder. For SLAM I need the encoder version (JGB37-520 Hall, 6 wires). I have to confirm at the store or source the encoder variant separately before I buy.


Project: ROVER "Target Fidelity"

Name: SEBDev

Date: 06/30/2026

Page 13

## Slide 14

My FEA plan (targets)

I'll run Static Stress in Fusion on the parts that carry the most. These are the numbers the design SHOULD hit - I haven't solved it yet, so I'll swap in the real values once I run it.

Part | Load | Target SF | Peak stress | Deflection | Pass
Rocker (Al) | 235 N | 3-5 | 60-90 MPa | <2 mm | SF>=2.5
Bogie (Al) | 177 N | 4-6 | 40-60 MPa | <1.5 mm | SF>=2.5
Joint A (PETG) | 235 N | 2.5-4 | 15-25 MPa | <1 mm | SF>=2.0
Joint B (PETG) | 177 N | 3-5 | 10-20 MPa | <1 mm | SF>=2.0
Axle D12 (steel) | 118 N/side | 2-3 | 80-140 MPa | <3 mm | SF>=2.0

How I'll read it

Aluminum arms should be comfy (SF 3-5). If the rocker drops under 2.5 I'll step up to D28 tube.
PETG joints are the tight ones - I'll mesh finely at the socket roots.
The D12 axle is the one I'm watching - a 700 mm rod can flex. If deflection > 3 mm I'll go D15 or add a center support.

Motion study comes first
Before FEA I check the kinematics: the two rockers move in opposition, the bogie swings free, nothing collides. 11 revolute joints total. If the ball joints on the differential are set right the linkage transmits with no Motion Link - I already got that working.

Project: ROVER "Target Fidelity"

Name: SEBDev

Date: 06/30/2026

Page 14

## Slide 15

Bill of materials

Prices in COP from I+D (Didacticas Electronicas, Medellin) and Bigtronica, early 2026. Ballpark - they drift.

Part | Qty | Note / price
JGB37 12V 50RPM (40 kg*cm) | 6
BTS7960 43A driver | 2
MG996R servo | 4
PCA9685 PWM driver | 1
Al round tube D25x2 | ~1.6 m
Al round tube D20x2 | ~0.9 m
Steel rod D12 x 700 | 1
Aluminum 2020 extrusion | ~3 m
Rod-end ball joints M5 | 4
Rim (PETG) + tire (TPU) | 6 ea
Raspberry Pi 4 + Arduino R4 | 1 ea

Filament + where I'm sourcing
~600 g PETG (joints, mounts, rims, bearing blocks, balancin, clamps) + ~250 g TPU 95A (tires). All suppliers are in Medellin: I+D (Suramericana + CC La Cascada), Bigtronica, El Palacio del Aluminio, Grupo Roldan, Electronilab. Steel rod + pins from any steel depot - I ask for 'barra calibrada D12'.

Project: ROVER "Target Fidelity"

Name: SEBDev

Date: 06/30/2026

Page 15

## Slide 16

Redesigning the wheel joint: bearing + real angles

Borrowing from a proven reference

Instead of designing the steering knuckle from scratch, I pulled the geometry from the "Mars Rover Perseverance Replica" build (SolidWorks files, now in the Referencia folder) and reused their Servo coupler, Servo Horn, and Wheel Joint parts as-is. Checked my 37 mm gear motor (6 mm D-shaft, 31 mm bolt circle) against their "Wheel 1 Joint p2" cavity - exact fit, no scaling needed.

The knuckle needed a bearing between the servo coupler and the wheel shaft. Instead of buying one, I generated a print-in-place ball bearing in OpenSCAD (BOSL2 library) sized to the "635" standard - ID5/OD19/W6mm, dumbbell rollers, 0.15mm clearance. Prints straight into the socket, no purchased part.

A bearing I don't have to buy

Getting the angle from the real model, not the docs

The socket has to tilt so the servo's steering axis comes out perfectly vertical even though the rocker/bogie arm it sits on is angled. I stopped trusting my old notes and computed the real angle straight from the live Fusion assembly (walking occurrence.transform2 chains): 30deg at the front/rocker corner, 10deg at the rear/bogie corner.

Mirrored for the other side
Once the geometry was right on one side, I mirrored all three knuckle variants (JuntaLlanta, JuntaLlantaEstatica, JuntaLlantaDireccion) across the chassis plane and saved them as their own files (...I suffix) - so the 6-wheel layout is properly symmetric instead of hand-copied angles.

Project: ROVER "Target Fidelity"

Name: SEBDev

Date: 08/09/2026

Page 16

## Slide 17

Getting a real quote for the shopping list

What a real quote actually costs

Got a real quote from I+D Didacticas Electronicas (Cotizacion S174842, COP $2,216,852 with IVA) - all 6 JGB37 motors, 3 BTS7960 drivers, the steering servos, 13m of 2020 aluminum profile, PETG/TPU filament, and more, nothing purchased yet. Updated bom_rover.csv line by line against the quote - prices that were rough guesses before are now marked "Cotizado" with the real numbers.

Page 13 left this open: whether I needed the Hall-encoder motor variant for SLAM odometry. Didn't have to chase it down - bought 2x 448 CPR optical encoders sized for the 37mm motor shaft instead, so odometry is solved independent of which JGB37 variant I run.

The encoder question, closed

New brain: one board instead of two

Swapped the planned Raspberry Pi 4 + Arduino R4 pair for a single Arduino UNO Q - 2GB RAM, 16GB eMMC, a Linux-capable Cortex-A53 side plus a realtime Cortex-M33 side on one board. One less board to wire and power, no separate microSD to manage.

Still pending
Chassis hardware (round tube, acrylic lid, most of the bolts), the battery + charger, and the lab sensors are not in bom_rover.csv yet - no real quote for them so far. This quote covers movilidad, chasis extrusion, filament, and the brain, but nothing has actually been ordered yet.


Project: ROVER "Target Fidelity"

Name: SEBDev

Date: 08/09/2026

Page 17

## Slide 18

Where I'm at & what's next

What's actually built

All three wheel-joint variants (JuntaLlanta, JuntaLlantaEstatica, JuntaLlantaDireccion) have their final socket geometry, sized and angled off the real assembly, plus mirrored left-side copies so the 6-wheel layout is symmetric. The steering knuckle carries a printed bearing instead of a bought one, and I validated the mount against a real MG995 servo in a standalone test assembly first.

Movilidad electronics, chassis extrusion, filament, and the brain are priced out in a real quote (bom_rover.csv, Cotizacion S174842) but nothing has been purchased yet. Still needed, no quote yet: round tube + steel axle for the differential, the acrylic/MDF lid, the battery + charger, and the lab module hardware (color sensor, pumps, syringe dispenser).

What's priced vs. still pending

Next up

Finish the 4 remaining wheel-corner assemblies as real linked-component Fusion assemblies (not flattened single-body hacks), using Ensamble llanta / Ensamble llanta Largo as templates. Then close out the differential/balancin hardware and start on the chassis build.

A trick worth keeping
For any live-assembly measurement (angles, positions), read it straight from occurrence.transform2 chains in the actual model instead of trusting old notes - the model changes faster than the docs do.

Project: ROVER "Target Fidelity"

Name: SEBDev

Date: 08/09/2026

Page 18

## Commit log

2026-06-25 Add STL parts, move zip, and update README
    Add multiple new STL files for suspension, steering, and wheels (Parts/STL-parts/{Bogie,Direccion,Llantas}) and relocate FusionV1pieces.zip from FusionParts/ to Parts/. Remove empty R markers (Fusion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
    [Direccion_Der.stl, Direccion_Izq.stl, JuntaLlanta.stl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]
2026-06-30 Revise printed parts section in README
    Updated material and printing notes for various parts in the README.
2026-07-01 Add BOM and expand README (differential)
    Add a new BOM (BOM/bom_rover.csv) listing components and quantities. Update README with a real differential (balancín + bieletas), expanded parts/specs (chassis size, estimated mass bumped to ~30 kg)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
    [bom_rover.csv]
2026-07-06 Update BOM with prices and add rover images
    Replace BOM/bom_rover.csv with a detailed costed BOM (new headers: Categoria;Parte;Cantidad;PrecioUnitario_COP;Subtotal_COP;Fuente;Estado), added unit prices, subtotals, sources and status flags (delimiter changed to semicolons). Add two rover images (docs/img/rover_dev2_1.png, docs/img/rover_dev2_front.png) and update README.md to embed those images and adjust the credits section.
    [bom_rover.csv]
2026-08-09 Update BOM from real purchase, add wheel-joint STLs, journal pages, and steering animation
    - BOM: reconcile bom_rover.csv against the real invoice (Pedido S174842) -
    motors, drivers, servos, 2020 profile, filament, and the Arduino UNO Q
    brain are now marked Comprado with real prices; everything else stays
    Pendiente.
    - Parts/STL-parts/Bogie: export the final steering-knuckle geometry
    (printed bearing + real 30/10deg angles) plus mirrored left-side
    variants (JuntaLlanta/Estatica/Direccion + ...I), replacing the
    pre-redesign STLs.
    - Journal: add 3 new pages (wheel-joint redesign, the real order + brain
    swap, current status/next steps) and update the Table of Contents.
    - README: ne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
    [JuntaLlanta.stl, JuntaLlantaDireccion.stl, JuntaLlantaDireccionI.stl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]
2026-08-09 Fix BOM: quote, not a purchase; fill in missing journal images
    - The I+D pricing was a quotation (Cotizacion S174842), not a completed
    order - bom_rover.csv, README, and the journal's real-order page now
    say Cotizado/quoted throughout instead of Comprado/bought.
    - Fill the 6 empty image placeholders left in the journal (intro hero,
    rocker-bogie arm geometry, printed tube joint x2, motor cavity fit,
    filament/printed-parts) with real Fusion screenshots and renders.
    - Journal cover was already a single flattened picture (not editable
    components) - confirmed, no change needed there.
    [bom_rover.csv]
2026-08-09 Fix BOM CSV quoting; add temp PPTX
    Escape the double-quote in BOM/bom_rover.csv for the OLED part name by quoting the field and doubling the internal quote. A trailing empty CSV row was also added. Additionally, a temporary Office autosave/lock file was added to Journal (~$Librito_Rover x_x (CreacionSistemaMecanico) .pptx). The PPTX appears to be an editor temp file and can be removed if unintended.
    [bom_rover.csv]
2026-08-11 README: fix stale 1:1 differential figure, add honest Status section
    - The "180 mm" balancin/clamp figure was from an early planning stage;
    the real balancin arm measures 325 mm (confirmed off the live
    Diferencial part) - updated the 1:1 rule accordingly.
    - Replaced the empty "The demo - [coming soon]" placeholder with a
    Status table that says plainly what's built, priced, and not started
    yet (including firmware), instead of a bare TODO.
    - Fixed the Journal link's URL encoding (spaces/parens in the filename).
2026-08-11 Trim BOM to quoted items only, fix CSV format, remove stray lock file
    - BOM/bom_rover.csv: comma-delimited (was semicolon, which silently
    breaks standard CSV parsers - likely why an external review flagged
    it as broken), UTF-8 without BOM mark, new Montaje column stating
    where each part physically mounts. Dropped every row that isn't
    actually quoted (Pendiente/WIP/Fijo placeholders) per instruction -
    the CSV now only lists the 24 items priced in Cotizacion S174842.
    - README and journal pages 17/18 updated to match: no more references
    to a "Pendiente" list inside the BOM itself.
    - Removed an accidentally-committed PowerPoint lock file
    (~$Librito_Rover...pptx) and added .gitignor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
    [bom_rover.csv]
